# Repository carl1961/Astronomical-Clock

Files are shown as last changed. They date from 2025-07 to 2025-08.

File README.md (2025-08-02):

# Astronomical Clock By illusionmanager
https://www.instructables.com/Astronomical-Clock-1/  



Read and follow illusionmanager instrutions

This project is 150% size of original



## Features (Optional)

- **Easy WiFi Configuration:** No need to hardcode WiFi credentials.
- **Automatic Reconnection:** The device automatically tries to connect to the last known WiFi network on startup.
- **Display** No need to connected to computer to see progress.
## Hardware Requirements

- ESP32-C3 Super mini Development Board

## Pinout

 **ESP32-C3 Super Mini Pin**
 
(*) or Optional

VCC	5V-----------------PIN_5

GND--------------------PIN_6

VCC_3V3----------------PIN_7

Pin_4 *----------------PIN_8

Pin_3 *----------------PIN_9

Pin_2 *----------------PIN_10

Pin_1 *----------------PIN_20

Pin_0 *----------------PIN_21

#TMC2209

**originl setup**

EN--------------------------VM_5V

MS1-------------------------GND

MS2-------------------------M2B  **orange wire stepper motor 28BYJ-48**

SRD-------------------------M2A  **pink wire stepper motor 28BYJ-48**

RX_PIN 9--------------------M1A  **yellow wire stepper motor 28BYJ-48**

TX--------------------------M1B  **blue wire stepper motor 28BYJ-48**

STEP-PIN_6------------------VIO_5V

DIR-PIN_5-------------------GND

**I had to reverse motor, reverse wires on stepper motor 28BYJ-48**

EN-------------------------VM_5V

MS1------------------------GND

MS2------------------------M2B  **blue wire stepper motor 28BYJ-48**

SRD------------------------M2A  **yellow wire stepper motor 28BYJ-48**

RX-PIN_9-------------------M1A  **pink wire stepper motor 28BYJ-48**

TX-------------------------M1B  **orange wire stepper motor 28BYJ-48**

STEP-PIN_6-----------------VIO_5V

DIR-PIN_5------------------GND

- **ESP32 C3 with ILI9341 display (Optional)**

**TFT Display**	   **ESP32-C3 Super Mini Pin**

VCC--------------------------5V

GND--------------------------GND

CS---------------------------Pin 3

DC---------------------------Pin 1

RST--------------------------Pin 0

SCK--------------------------Pin 2

SDI (MOSI)-------------------Pin 4

LED VCC----------------------3V3

## Installation & Usage

1.  **Install Arduino IDE and ESP32 Core:** Make sure you have the Arduino IDE installed and the ESP32 board support package added.
    Arduino IDE, go to File/Preferences and add "https://raw.githubusercontent.com/espressif/arduino-esp32/gh-pages/package_esp32_dev_index.json" 
2.  **Install Libraries:** Open the Library Manager in the Arduino IDE and install the following library:
    -   `WiFiManager` by tzapu
3.  **Configure Pins (Optional):** If you are using different GPIO pins.
4.  **Upload the code:** Connect your ESP32 board to your computer, select the correct board and port in the Arduino IDE, and upload the sketch.

## AP Option

1.  **Initial Setup:**
    -   On the first boot, or if a WiFi connection fails, the ESP32 starts a WiFi Access Point with the SSID **"AstroClockAP"** and the password **"12345678"** if you enabled it in firmware, default is no password.
   
2.  **Configuration:**
    -   Connect to the "AstroClockAP" WiFi network from your computer or smartphone.
    -   Once connected, a captive portal should automatically open in your web browser. If not, open a browser and navigate to `192.168.4.1`.
    -   Select your home WiFi network (SSID) from the list, enter the password, and click save.
    
3.  **Connection:**
    -   The ESP32 will then try to connect to the network you configured.
    -   If successful, the "Connected" LED will light up.
    -   The WiFi credentials are saved in non-volatile memory and will be used for future connections.
4.  **Resetting WiFi:**
    -   To clear the saved WiFi credentials, press and hold the "Reset WiFi" button. You can do this either when the device is booting up or while it is running. The device will restart and enter configuration mode again.

## Dependencies
For Optinal Wifi AP
-   [WiFiManager](https://github.com/tzapu/WiFiManager) 
-   [Setting  TZ](https://github.com/esp8266/Arduino/blob/master/cores/esp8266/TZ.h)
-   
For Optional Display
-   [Adafruit_ILI9341](https://github.com/tzapu/WiFiManager) 
-   [Adafruit_GFX](https://github.com/tzapu/WiFiManager)

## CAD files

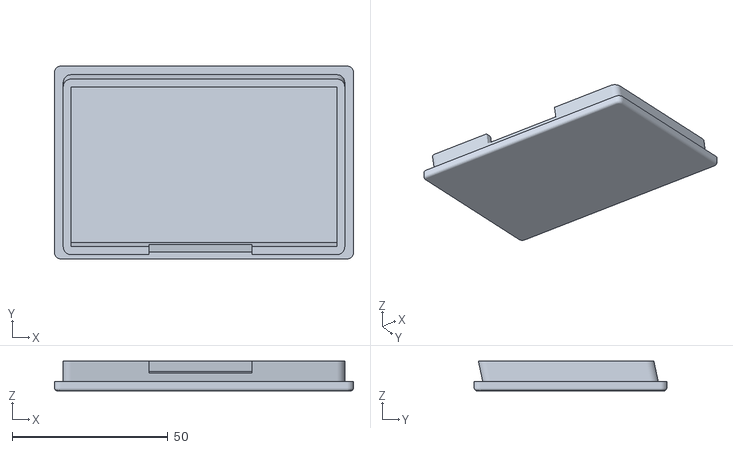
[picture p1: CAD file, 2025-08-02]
150-percent/Display Case 2.8 ILI9341/TFT-Bottom.stl
96.0 x 61.9 x 9.60

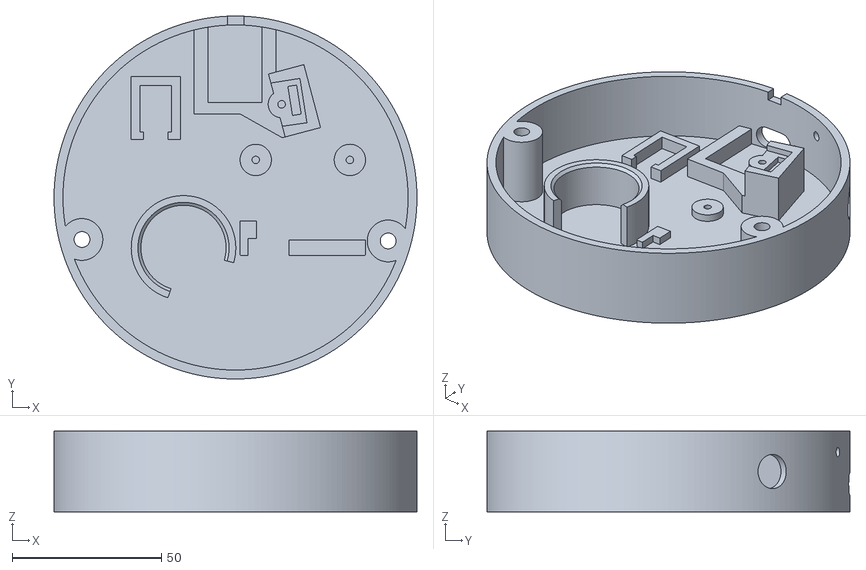
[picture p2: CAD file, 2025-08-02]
150-percent/motor housing-Y-V2.stl
121.5 x 121.5 x 27.0

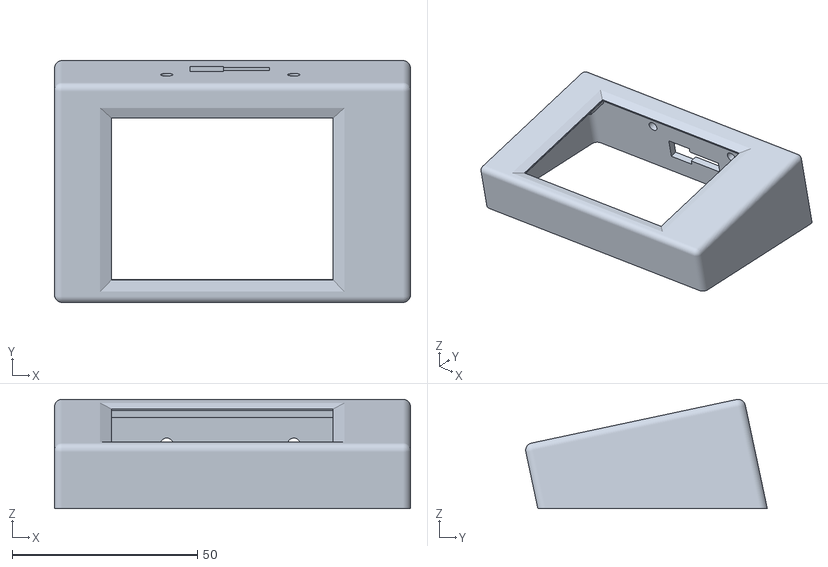
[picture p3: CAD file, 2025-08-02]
150-percent/Display Case 2.8 ILI9341/TFT-Top.stl
96.0 x 65.2 x 29.5

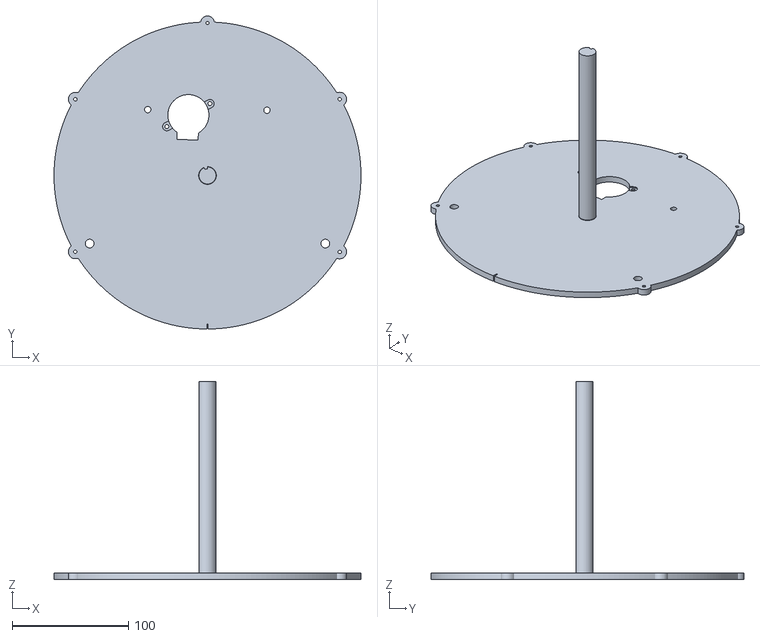
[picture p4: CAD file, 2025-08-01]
150-percent/clock base-N-B-Mounted-35BYJ46-84.stl
264.0 x 269.2 x 170.5

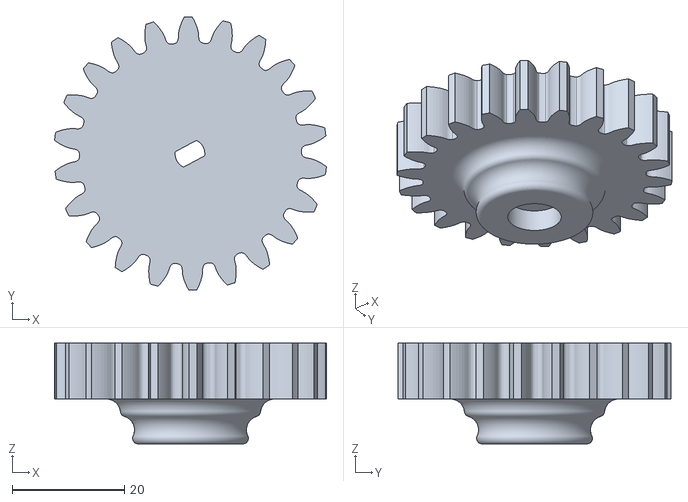
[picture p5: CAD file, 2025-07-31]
150-percent/motor gear-B V2.stl
48.5 x 48.8 x 18.0

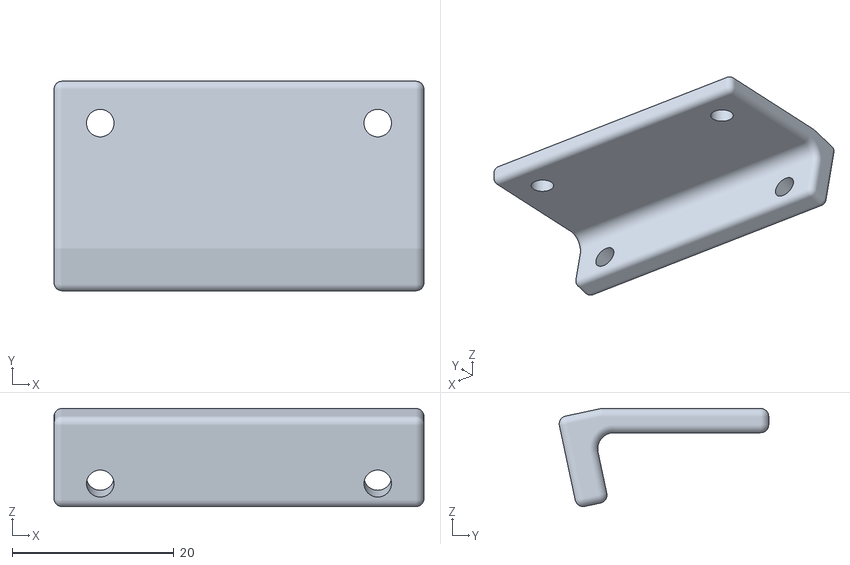
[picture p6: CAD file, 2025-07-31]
150-percent/Display Case 2.8 ILI9341/Mount.stl
45.7 x 25.9 x 12.1

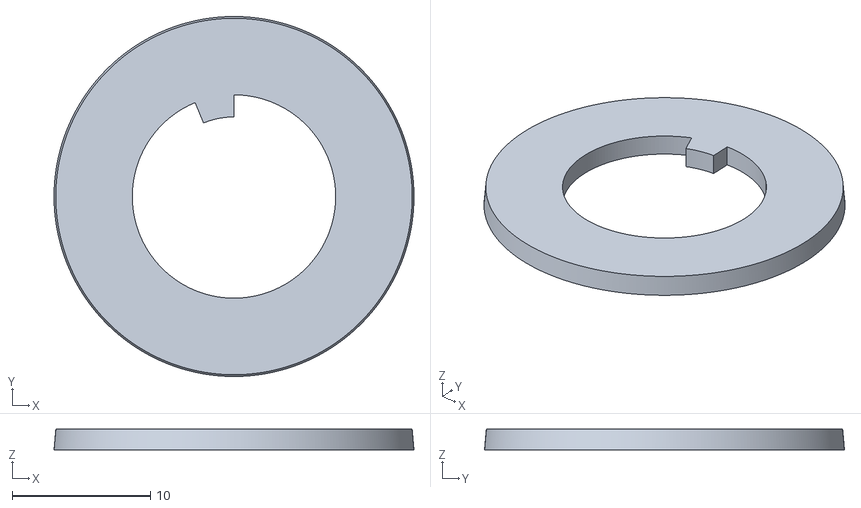
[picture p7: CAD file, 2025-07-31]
150-percent/jupiter spacer.stl
26.0 x 26.0 x 1.50

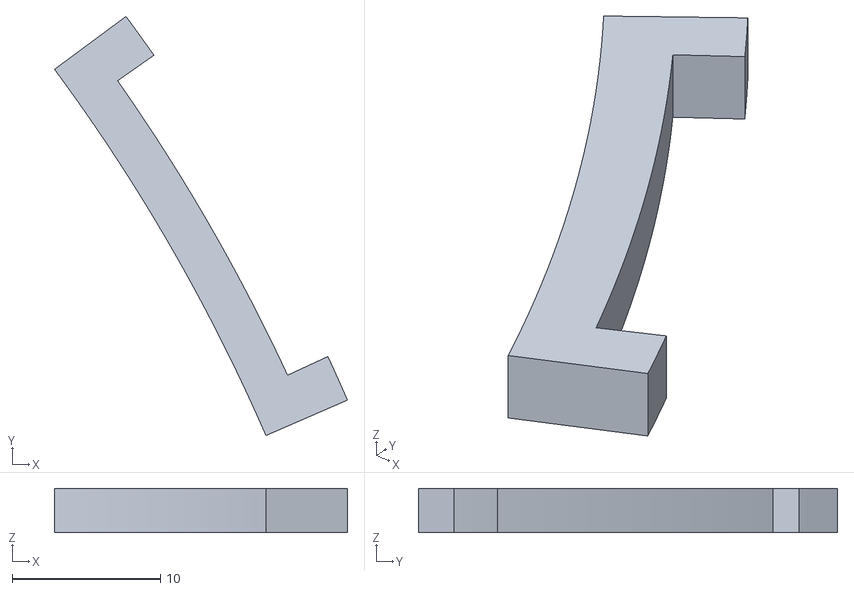
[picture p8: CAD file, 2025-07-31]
150-percent/zodiac holder 2-B.stl
19.8 x 28.3 x 3.00

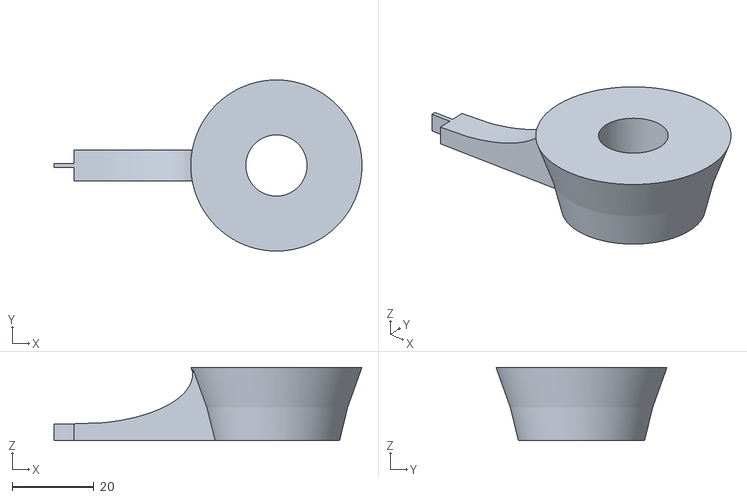
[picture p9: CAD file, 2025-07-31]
150-percent/neptune arm part2-B.stl
75.6 x 42.0 x 18.0

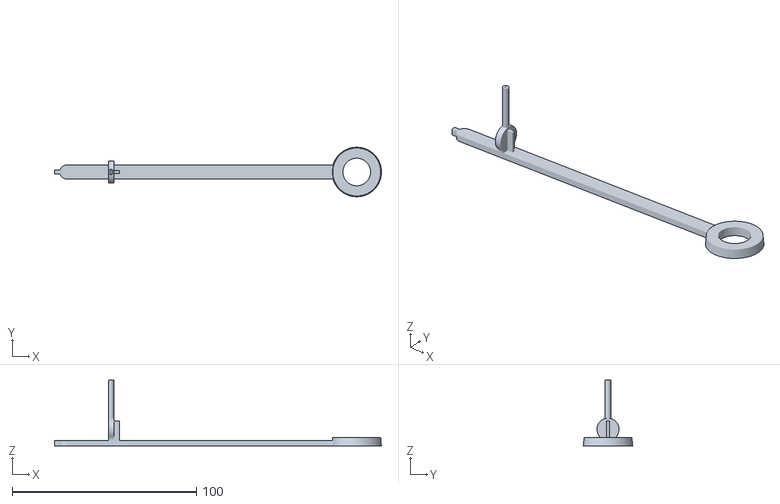
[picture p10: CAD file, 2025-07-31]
150-percent/saturn arm-M-B.stl
177.6 x 26.9 x 35.7

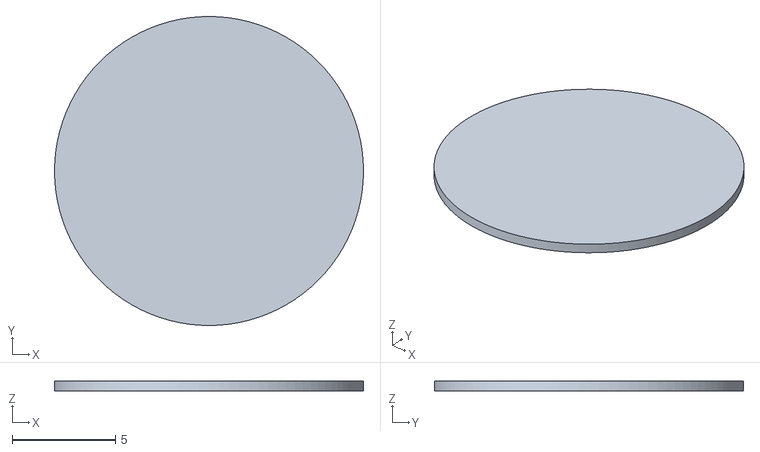
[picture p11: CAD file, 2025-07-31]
150-percent/nodebase1-B.stl
15.0 x 15.0 x 0.48

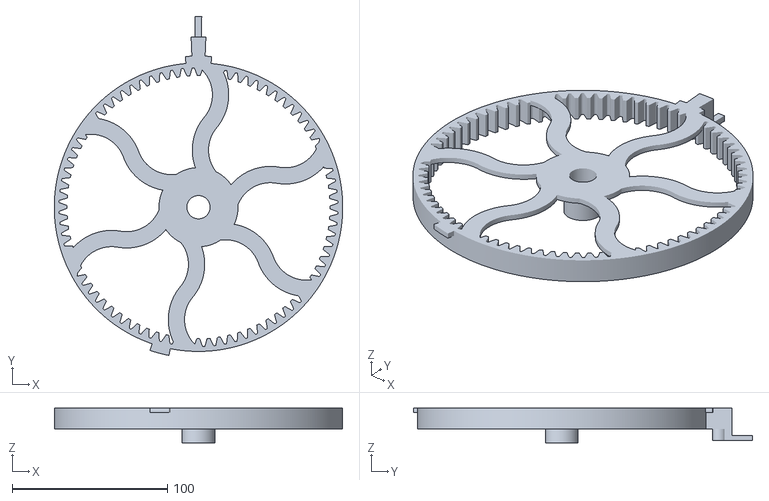
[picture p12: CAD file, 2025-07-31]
150-percent/sunset wheel-B-Magnet-6mmx6mm .stl
186.0 x 218.6 x 22.5

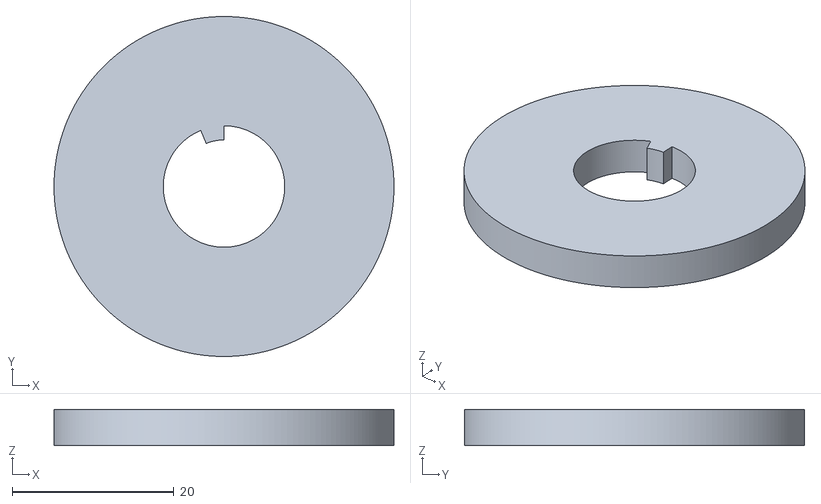
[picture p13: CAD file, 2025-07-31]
150-percent/node spacer-Y.stl
42.0 x 42.0 x 4.50

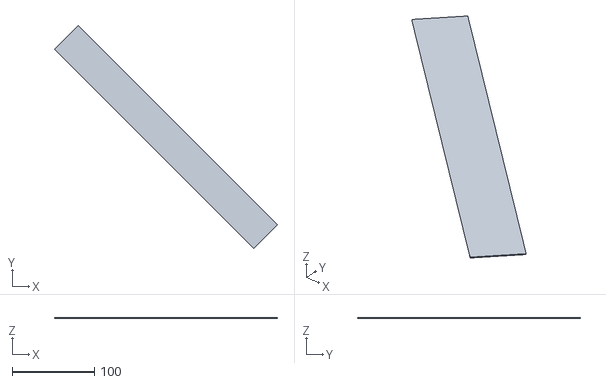
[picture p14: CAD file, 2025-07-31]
150-percent/time scale empty part-N.stl
271.7 x 271.7 x 0.7

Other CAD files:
150-percent/motor housing-Y-V2-35BYJ46.stl
150-percent/Display Case 2.8 ILI9341/motor housing-Y-V2-Display-35BYJ46.stl
150-percent/Display Case 2.8 ILI9341/motor housing-Y-V2-Display.stl
150-percent/mars arm-M-B.stl
150-percent/Indicator-N-O.stl
150-percent/brake disk base-B.stl
150-percent/brake disk spacer-N-Y.stl
150-percent/brakedisk-N-Y.stl
150-percent/clock base-N-B-Mounted-Suports.stl
150-percent/clock base-N-B-Mounted.stl
150-percent/clock base-N-B.stl
150-percent/clock foot 1-Y.stl
150-percent/clock foot 2-Y.stl
150-percent/earth arm-M-B.stl
150-percent/earth spacer-Y.stl
150-percent/earth sphere.stl
150-percent/jupiter arm-M-B.stl
150-percent/mars spacer-Y.stl
150-percent/mars sphere.stl
150-percent/mercury arm-M-B.stl
150-percent/mercury-spacer-Y.stl
150-percent/moon phase base-B.stl
150-percent/moon phase symbols-Y.stl
150-percent/moon rise arm-N-B.stl
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

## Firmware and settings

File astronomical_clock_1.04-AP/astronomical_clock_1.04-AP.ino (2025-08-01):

// this code is written by illusionmanager in the year 2024
// it is for the eclipse spinner (astronomical clock)
// software version 1.04

// you'll need to program the MYSSID and MYPASSKEY to match your network credentials
// as well as the longitude and lattitude and timezone
//#define MYSSID ""
//#define MYPASSKEY ""


// pick timezone from TZ.h (https://github.com/esp8266/Arduino/blob/master/cores/esp8266/TZ.h)
//#define TIMEZONE "CET-1CEST,M3.5.0,M10.5.0/3"
//#define TZ_America_Chicago	PSTR("CST6CDT,M3.2.0,M11.1.0")
#define TIMEZONE "CST6CDT,M3.2.0,M11.1.0"
//LONGITUDE -90.4345  LATTITUDE 30.5806 https://www.mooncalc.org/ https://www.moongiant.com/calendar/
#define LONGITUDE -90.43  //6.57
#define LATTITUDE 30.58   //53.22

// This must be my ugliest code I've ever written. Sorry for that.

// in the main loop there is commented out testroutine.
// if you enable that the clock should rotate and move everything at 90 degrees angle
// from eachother. Perhaps comment out the print command in the rotate routine as well and use
// #define NOWIFI so it doesn't waste time getting data from NASA.
// if it doesn't show the planets exactly at 90 degrees you need to calibrate the numbers stored in touchValues.
// (( however if they are aligned, but more in a 60 and 120 degree pattern, you have mounted the sunrise pointer
// or time wheel on the wrong site of the tabs on the sunrise wheel))
// Calibrate by first hitting the 'r' key to reset the clock
// enter the value close the one (but a little less) currently in touchValues[0].
// it should move mercury to exacly 0 degrees. But as you entered a slightly less value,
// rotate a bit more by entering -1 (it rotates 1 degree more). Note that when Mercury is at 0 degrees,
// the other planets are not because of the thickness of the tabs. When during the testrouting all the planets seem to
// be rotated by the same amount, this value for mercury is the one to change.
// When mercury is exactly at 0 degrees add the total rotation you did together and store that
// into touchValues[0] (should be a negative rotation!)
// Next is Venus, it needs to know how much to rotate in the oposite direction until it is just about to
// start rotating Venus. It also needs to compensate a little for the thickness. Those values are stored in
// offsetValues. So rotate a fraction more to set Venus in the 0 orientation and set that value in offsetValues, but
// for now, those values are based on the design, and should be almost perfect, so you can leave them alone, but you might need
// to adjust them.

//  -1075 puts sunset directly opposite sunrise; rotate a bit further to set the time difference between sunset and sunrise
// 880 puts sunrise at 00:00 ; rotate a bit further to set sunrise
// -697 brings moon set to 00:00; rotate a bit further to set moonset
//
// 360 starts pushing moon rise pointers. one is at 10 degrees (1h33') before moonset. pushing it further moves it back towards 00:00
// so move it back by the difference between moonrise and moonset - 10 degrees, keeping in mind the 00:00 crossing
// if it passes 0 the other moonrise pointer takes over at 24:00
// At this point the time shown is determined by the moonphase, which also sets the final value of orient

float touchValue[] = { -341, 4107, -3750, 3395, -3038, 2677, -2319, 1959, -1602, 1247.5, -1076, 883, -697.5, 361.5 };
float offsetValue[] = { -3.1, 2.2, -1.78, 1.3, -0.8, 0.7, -0.65, 1.5, 0.5, 3 };
// motor appears a bit stronger with more microsteps, so I use 32 instead of 8
#define MICRO_STEPS 32
// for some the 28BYJ-48 has ratio 64*403/405 = 63.6839506
// multiply that by 32 results in 2037.88642 steps to go around once.
// but mine apparently does need exactly 2048 steps to go around.
// It varies, so check your motor
// multiplied by the gear ratio in this clock 80/22 results in 7447.272727 full steps
// for the clock to go around once
// clock has ratio 80/22 = 3.636363
// 7447.27272727 steps to go around once
#define STEPS_PER_DEGREE 20.686868
#define DEGREE_PER_STEP 0.048339843


// should have been 180, but on my clock it is slightly more. Probably has to do with the thickness of the clockface
#define DEGREE_PER_HOUR (181.0 / 24)

// ZERO_OFFSET should be positive
#define ZERO_OFFSET (189.2f)
#define DIR_PIN 5
#define STEP_PIN 6
#define ENABLE_PIN 7
#define LED_PIN 8

// stop_pin connected to #9 as this has an internal pull-up resistor.
// also to be used for triggering boot mode.
// if you need to "press" the boot switch to load a program, just rotate the sunrise wheel
// so the magnet is exactly at the back and power on. If you want to run the program, make
// sure the magnet isn't exactly at the back during power on.
#define STOP_PIN 9

// you might need to reduce the MAX_SPEED if you motor cannot handle the speed.
#define MAX_SPEED 500
// even though there is no mechanical reason not to go faster, somehow the free spinning pointers and time scale
// do move when going faster.
#define PRECISE_SPEED 400
#define ACCELERATION 150

#define SERIAL_BAUD_RATE 115200
#define RUN_CURRENT_PERCENT 100

// set this close to 0 in production version
#define SHORT_DELAY 2500

//#define NOWIFI
#define PLANETSPINNER "       Eclipse Spinner\n\n       by illusionmanager\n (youtube.com/@illusionmanager)\n\n"

#include <Arduino.h>
#include <TMC2209.h>
#include <WiFiClientSecure.h>
//#include <ESPAsyncWebSrv.h>
#include <time.h>
#include <AccelStepper.h>
// AP
#include <WiFiManager.h>  // https://github.com/tzapu/WiFiManager

WiFiManager wifiManager;

AccelStepper stepper(AccelStepper::DRIVER, STEP_PIN, DIR_PIN);

// UART connection to controller
HardwareSerial& serial_stream = Serial0;

// Instantiate TMC2209
TMC2209 stepper_driver;

// stores the absolute orientation of the mercury, which drives the rest
float orient = 0;

bool debug = false;
// for no really good reason all the relevant status info is stored in global variables.

// holds the orientation of each planet;
float planet[] = { 90, 180, 270, 90, 180, 270, 90, 180, 270 };
String planetName[] = { "Mercury", "Venus", "Earth", "Mars", "Jupiter", "Saturn", "Uranus", "Neptune" };
float sunrise, sunset, moonrise, moonset;
float moonphase, moonperifocus;  // perifocus is the position of the moon in its oribt measured for the ascending node
// next variables hold the current local time.
int year;
uint8_t month;
uint8_t day;
uint8_t hour;
uint8_t minute;
float currenttime;
// mark is set by the doTime routine and indicates orientation of the tab on the moonphase brake wheel
// ( to be avoided during normal clock operation )
float mark;
float timeOffset = 0.0;
float lattitude = LATTITUDE;
float longitude = fmod(LONGITUDE + 360, 360);
WiFiClientSecure client;

volatile bool stopped;  // used with interrupt routine to detect home position
bool initDoneToday = false;

void rotate(float deg) {
  // positive is counterclockwise, but the stepper library has that as negative
  if (debug) Serial.printf("rotating %4.2f\xC2\xB0\n", deg);
  stepper.move((-deg / DEGREE_PER_STEP) * MICRO_STEPS);
  stepper.runToPosition();
}

void rotateTo(int dir, float newOrient) {
  // rotates from the current orientation (stored in variable orient)
  // it assumes the pointer/planet is just about to move (should be touching)
  // to the neworientation, in the given direction (-1 or 1)
  newOrient = fmod(newOrient + 360, 360);
  if (dir > 0) {
    if (newOrient <= orient) {
      rotate(360 + newOrient - orient);
    } else {
      rotate(newOrient - orient);
    }
  } else {
    if (newOrient >= orient) {
      rotate(-360 + newOrient - orient);
    } else {
      rotate(newOrient - orient);
    }
  }
  orient = newOrient;
}

void adjustOrient(float delta) {
  orient = fmod(orient + 360 + delta, 360);
}

void getTime(void) {
  struct tm timeinfo;
  getLocalTime(&timeinfo);
  year = timeinfo.tm_year + 1900;
  month = timeinfo.tm_mon + 1;
  day = timeinfo.tm_mday;
  hour = timeinfo.tm_hour;
  minute = timeinfo.tm_min;
  currenttime = hour + minute / 60.0 + timeinfo.tm_sec / 3600.00;
  currenttime += timeOffset;
  if (currenttime >= 24) {
    day++;
    currenttime -= 24;
  }
  hour = (int)currenttime;
  minute = (int)((currenttime - hour) * 60);
}

// returns offset with GMT in minutes
int getTimeDifference(void) {
  struct tm gmtTimeInfo, localTimeInfo;
  time_t now;

  time(&now);                    // Get current time
  gmtime_r(&now, &gmtTimeInfo);  // Get GMT time
  int gmtmin = gmtTimeInfo.tm_hour * 60 + gmtTimeInfo.tm_min;
  localtime_r(&now, &localTimeInfo);  // Get local time
  int localmin = localTimeInfo.tm_hour * 60 + localTimeInfo.tm_min;
  if (gmtTimeInfo.tm_yday != localTimeInfo.tm_yday) {
    return (localmin - gmtmin + 24 * 60);
  } else {
    return (localmin - gmtmin);
  }
}

float getFloat(void) {
  // the client.parseFloat is buggy and cannot handle floats with lots of decimal places
  float X = client.parseInt();  // stops at decimal point
  char c = client.read();
  int fraction = 0;  // read 6 digits of the fractional part
  for (int i = 0; i < 6; i++) {
    c = client.read();
    fraction = fraction * 10 + c - '0';
  }
  client.parseInt();  // ignore the rest
  float exponent = client.parseFloat();
  if (X > 0) {
    X = (X + fraction * 0.000001) * pow(10, exponent);
  } else {
    X = (X - fraction * 0.000001) * pow(10, exponent);
  }
  return X;
}

float getOrientation(int id, int center, int lyear ,uint8_t lmonth,uint8_t lday) {
  // Nasa id mercury = 199, venus = 299, earth = 399, etc.
  // moon= 301, center = 10 for sun.
  client.setInsecure();
  delay(100);
  if (client.connect("ssd.jpl.nasa.gov",443)) {
    if (debug) Serial.printf("https://ssd.jpl.nasa.gov/api/horizons.api?format=text&COMMAND=%%27%d"\
      "%%27&OBJ_DATA=%%27NO%%27&MAKE_EPHEM=%%27YES%%27&EPHEM_TYPE=%%27VECTOR%%27&CENTER=%%27500@%d%%27&TLIST=%%27"\
      "%d-%d-%d 12:00%%27&QUANTITIES=%%271%%27 HTTP/1.0\n", id, center, lyear,lmonth,lday);
    client.printf("GET https://ssd.jpl.nasa.gov/api/horizons.api?format=text&COMMAND=%%27%d"\
      "%%27&OBJ_DATA=%%27NO%%27&MAKE_EPHEM=%%27YES%%27&EPHEM_TYPE=%%27VECTOR%%27&CENTER=%%27500@%d%%27&TLIST=%%27"\
      "%d-%d-%d 12:00%%27&QUANTITIES=%%271%%27 HTTP/1.0\n", id, center, lyear,lmonth,lday);
    client.println("Connection: close");
    client.println();
    // read all headers
    while (client.connected()) {
      String line = client.readStringUntil('\n');
      if (line == "\r") { // Headers received
        break;
      }
    }
    // skip text until $$SOE is found
    while (client.connected() && !client.find("$$SOE"));
    if (!client.available()) {
      Serial.printf("!!! no data for %d !!!\n",id);
      return 0;
    }
    while (client.connected() && !client.find("X ="));
    float X = getFloat();
    while (client.connected() && !client.find("Y ="));
    float Y = getFloat();
    while (client.available()) {
      char c = client.read();
    }
    client.stop();
    return fmod(atan2(Y, -X) / 3.141592 * 180 + 360 + 90, 360);
  } else {
    Serial.println("Connection failed");
    // rotate a bit to indicate the error
    rotate(-20);
    rotate(20);
    rotate(-20);
    rotate(20);
    rotate(-20);
    rotate(20);
    delay(3000);
    return 0;
  }
  Serial.println("what???");
  return 0;
}

float getMoonPhase(int lyear, uint8_t lmonth, uint8_t lday) {
  Serial.printf("getting moon phase... ");
  float earth = getOrientation(399,10,lyear,lmonth,lday);
  float moon = getOrientation(301,399,lyear,lmonth,lday);
  float phase = fmod(moon-earth +360+180,360);
  Serial.printf("%0.2f\xC2\xB0\n", phase);
  return phase;
}

float getMoonNode(int lyear, uint8_t lmonth, uint8_t lday) {
  Serial.print("getting moon's argument of perifocus and true anomaly... ");
  client.setInsecure();
  delay(100);
  if (client.connect("ssd.jpl.nasa.gov",443)) {
    client.printf("GET https://ssd.jpl.nasa.gov/api/horizons.api?format=text&COMMAND=%%27%d"\
      "%%27&OBJ_DATA=%%27NO%%27&MAKE_EPHEM=%%27YES%%27&EPHEM_TYPE=%%27ELEMENTS%%27&CENTER=%%27500@399%%27&TLIST=%%27"\
      "%d-%d-%d 12:00%%27&QUANTITIES=%%271%%27 HTTP/1.0\n", 301, lyear,lmonth,lday);
    client.println("Connection: close");
    client.println();
    // read all headers
    while (client.connected()) {
      String line = client.readStringUntil('\n');
      if (line == "\r") {  // Headers received
        break;
      }
    }
    // skip text until $$SOE is found
    while (client.connected() && !client.find("$$SOE"));
    if (!client.available()) {
      Serial.println("!!! no data for the moon !!! ");
      return 0;
    }
    while (client.connected() && !client.find("W ="));
    float W = getFloat();
    while (client.connected() && !client.find("TA="));
    float TA = getFloat();
    while (client.available()) {
      char c = client.read();
    }
    client.stop();
    W = fmod(W + TA, 360.0);
    Serial.printf("sum of those is %0.2f\xC2\xB0\n", W);
    return W;
  } else {
    Serial.println("Connection failed");
    // rotate a bit to indicate the error
    rotate(-20);
    rotate(20);
    rotate(-20);
    rotate(20);
    rotate(-20);
    rotate(20);
    delay(3000);
    return 0;
  }
  Serial.println("what???");
  return 0;
}

void getPlanets(int lyear, uint8_t lmonth, uint8_t lday) {
  Serial.print("getting data from NASA....\n");
  for (uint8_t i = 0; i < 8; i++) {
    // default value in case connection fails
    planet[i] = fmod(i * 90, 360);
    Serial.print(planetName[i] + "...");
    planet[i] = getOrientation((i + 1) * 100 + 99, 10, lyear, lmonth, lday);

    Serial.printf(" %0.2f\xC2\xB0\n", planet[i]);
    // for some reason the clock produces a mirror image, so lets switch the orientation as an easy fix
    planet[i] = fmod(360 - planet[i], 360);
  }
}
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
void loop() {


  // try to do 8 full steps with the motor
  const float timestep = DEGREE_PER_STEP * 8 / DEGREE_PER_HOUR;  // almost 3 minutes
  float truestep;
  if (initNeeded == true) {
    initDoneToday = true;
    getTime();
    Serial.printf("Local time is %02d:%02d\n", hour, minute);
    getPlanets(year, month, day);  // stores data in array Planets[]
    moonperifocus = getMoonNode(year, month, day);
    moonphase = getMoonPhase(year, month, day);
    getRiseSet(10, year, month, day, sunrise, sunset);
    Serial.printf("sunrise %02d:%02d sunset %02d:%02d\n", (int)sunrise, (int)((sunrise - (int)sunrise) * 60), (int)sunset, (int)((sunset - (int)sunset) * 60));
    if (sunrise == -1) sunrise = 00.00;
    if (sunset == -1) sunset = 30;
    getRiseSet(301, year, month, day, moonrise, moonset);
    Serial.printf("moonrise %02d:%02d moonset %02d:%02d\n", (int)moonrise, (int)((moonrise - (int)moonrise) * 60), (int)moonset, (int)((moonset - (int)moonset) * 60));
    if (moonrise == -1) moonrise = 00.00;
    if (moonset == -1) moonset = -2.00;

    gohome();
    doPlanets();
    doMoon();
    getTime();
    prevtime = currenttime;
    doTime();
    Serial.println("Ready.");
    //timetestRoutine();
    stepper.setMaxSpeed(PRECISE_SPEED * MICRO_STEPS);
    stepper.setAcceleration(ACCELERATION * MICRO_STEPS / 2);
    initNeeded = false;
    //now = currenttime;
  } else {

    getTime();
    truestep = currenttime - prevtime;
    if (truestep < 0) truestep += 24;

    if (truestep > timestep) {
      if (debug) Serial.printf("prevtime %0.4f timestep %0.4f truestep %0.4f currenttime %0.4f\n", prevtime, timestep, truestep, currenttime);
      float now;
      now = prevtime + truestep;
      if (now >= 24) {
        if (mark < 0 || mark >= 24) {
          if (debug) Serial.printf("rotA %0.2f\n", (24 - truestep) * DEGREE_PER_HOUR);
          rotate((24 - truestep) * DEGREE_PER_HOUR);
        } else {
          if (debug) Serial.printf("rotB %0.2f\n", -360 + (24 - truestep) * DEGREE_PER_HOUR);
          rotate(-360 + (24 - truestep) * DEGREE_PER_HOUR);
        }
      } else {
        if (now > mark && now - mark < truestep) {
          //rotate around mark
          if (debug) Serial.printf("rotC %0.2f\n", 360 - truestep * DEGREE_PER_HOUR);
          rotate(360 - truestep * DEGREE_PER_HOUR);
        } else {
          if (debug) Serial.printf("rotD %0.2f\n", -truestep * DEGREE_PER_HOUR);
          rotate(-truestep * DEGREE_PER_HOUR);
        }
        if (now < 03.00) {
          initDoneToday = false;
        } else if (!initDoneToday) {
          initNeeded = true;
        }
      }
      prevtime = currenttime;
    }
  }
  delay(20);


  // for debugging and testing purposes, while in the main loop you can enter a number
  // and it will rotate by that many degrees
  // 'r' does the reset procudere
  // 't' sets all the planets at 90 degree angles, rise and set indicators to 06:00 and 18:00, and time to 12:00 (reset needed first)
  // 'n' turns eclipse spinner back to normal operation (does a full reset)
  // 'f' sets the normal (fast) speed
  // 's' sets the slow (half) speed
  // 'p' prints relevant data
  // '=' followed by an offset, adds some time to the real time (should be less<24 hour)
  // 'd' toggle print additional debugging info

  char inChar;
  inChar = 0;

  if (Serial.available()) {
    inChar = (char)Serial.read();
  }
  switch (inChar) {
    case 'r':
      gohome();
      break;
    case 't':
      for (int i = 0; i < 8; i++) {
        planet[i] = fmod(i * 90 + 90.0, 360);
      }
      moonperifocus = 90;
      moonphase = 270;
      sunrise = 06.00;
      sunset = 18.00;
      moonrise = 06.00;
      moonset = 18.00;
      currenttime = 12.00;
      gohome();
      doPlanets();
      doMoon();
      prevtime = currenttime;
      doTime();
      Serial.println("done. press any key to continue");
      while (!Serial.available()) {
        delay(20);
      }
      inChar = (char)Serial.read();
      break;
    case 'n':
      initNeeded = true;
      break;
    case 'q':  // ignore this one
      timetestRoutine();
      break;
    case 'd':
      debug = !debug;
      break;
    case 'f':
      Serial.printf("fast speed %d\n", MAX_SPEED);
      stepper.setMaxSpeed(MAX_SPEED * MICRO_STEPS);
      break;
    case 's':
      Serial.printf("slow speed %d\n", MAX_SPEED / 2);
      stepper.setMaxSpeed(MAX_SPEED * MICRO_STEPS / 2);
      break;
    case 'p':
      Serial.printf("Orient is %0.1f\n", orient);
      Serial.printf("Currenttime is %02d:%02d (%0.2f)\n", (int)currenttime, (int)((currenttime - (int)currenttime) * 60), currenttime);
      Serial.printf("Mark is at %02d:%02d (%0.2f)\n", (int)mark, (int)abs((mark - (int)mark) * 60), mark);
      Serial.printf("Planets are at %0.0f\xC2\xB0,%0.0f\xC2\xB0,%0.0f\xC2\xB0,%0.0f\xC2\xB0,%0.0f\xC2\xB0,%0.0f\xC2\xB0,%0.0f\xC2\xB0,%0.0f\xC2\xB0\n", planet[0], planet[1],
                    planet[2], planet[3], planet[4], planet[5], planet[6], planet[7]);
      Serial.printf("Moon perifocus is at %0.2f\xC2\xB0 Moonphase is %0.2f\xC2\xB0\n", moonperifocus, moonphase);
      Serial.printf("sunrise %02d:%02d sunset %02d:%02d\n", (int)sunrise, (int)((sunrise - (int)sunrise) * 60), (int)sunset, (int)((sunset - (int)sunset) * 60));
      Serial.printf("moonrise %02d:%02d moonset %02d:%02d\n", (int)moonrise, (int)((moonrise - (int)moonrise) * 60), (int)moonset, (int)((moonset - (int)moonset) * 60));
      break;
    case '.':
    case ':':
      fractionfactor = 0.1;
      hasfraction = true;
      break;
    case '-':
      sgn = -1;
      break;
    case '1':case'2':case'3':case'4':case'5':case'6':case'7':case'8':case'9':case'0':
      if (hasfraction) {
        fraction = fraction + fractionfactor * (inChar - '0');
        fractionfactor *= 0.1;
      } else {
        rot = rot * 10 + (inChar - '0');
      }
      break;
    case '=':  // for my personal debugging only
      doOffset = true;
      Serial.printf("offset true\n");
      break;
    case '\n':
      if (doOffset) {
        timeOffset = rot + fraction;
        Serial.printf("timeoffset %0.2f\n", timeOffset);
        doOffset = false;
      } else if (rot + fraction > 0.001) {
        rotate(sgn * (rot + fraction));
      }
      sgn = 1;
      rot = 0;
      hasfraction = false;
      fraction = 0.0;
      break;
  }
}

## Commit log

2025-07-31 updated files
    added files
    [Indicator-N-O.stl, brake disk base-B.stl, brake disk spacer-N-Y.stl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]
2025-07-31 Updated files
    [Mount.stl, TFT-Bottom.stl, TFT-Top.stl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]
2025-08-01 35BYJ46 motor parts
    [clock base-N-B-Mounted-35BYJ46-84.stl, motor housing-Y-V2-35BYJ46.stl, motor housing-Y-V2-Display-35BYJ46.stl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]
